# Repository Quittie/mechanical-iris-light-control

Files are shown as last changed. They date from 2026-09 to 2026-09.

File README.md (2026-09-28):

# Mechanical Iris for Light Intensity Control

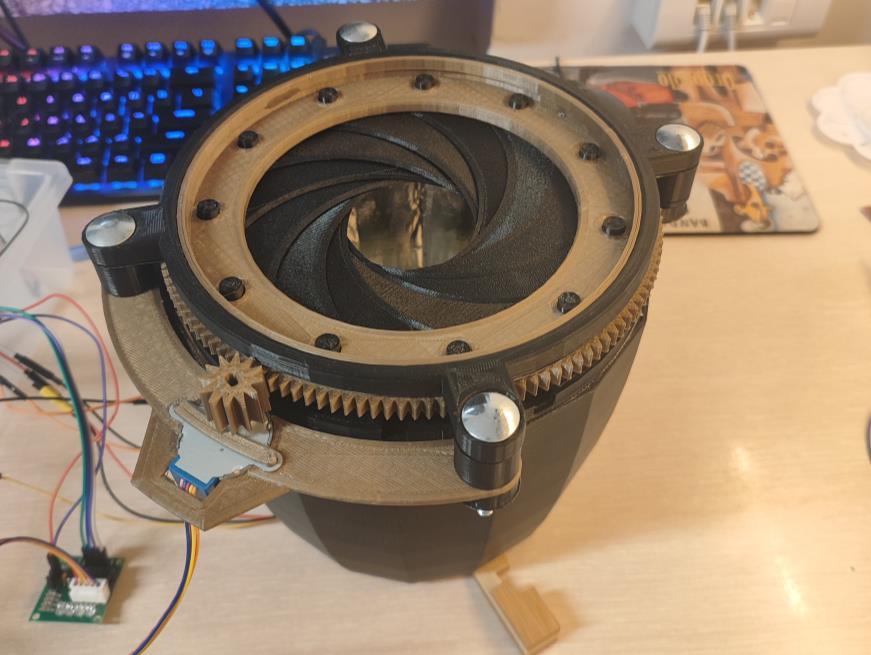
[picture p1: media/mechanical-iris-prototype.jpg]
Built mechanical iris


Microprocessor Systems course project, Poznań University of Technology, 2024/25.  
**Authors:** Piotr Trusiewicz and Michał Pietrzak.

The course assignment was to build an automatic regulation system. Michał and I chose to regulate the light level inside a chamber with a light sensor. A stepper motor opens or closes a printed mechanical iris, and an LED provides additional light when the aperture alone cannot reach the requested value. The target is set with a rotary encoder. An LCD shows the target and the reading from the sensor.

[Demonstration video 1](media/iris-demo-1.mp4) · [Demonstration video 2](media/iris-demo-2.mp4)

## My contribution

This was a team project, and I took part in the overall build and testing. My main responsibility was to choose a practical way to control how much light enters the chamber. I found [sketchpunk's Mechanical Iris](https://www.thingiverse.com/thing:773759) as a starting point, manually recreated and adapted the 3D design in Autodesk Inventor, assembled the mechanism, and fitted the electronic components into the prototype. The work described in our report includes changes to the stepper motor mount, the gear and the iris leaves.

The project and report are credited to both authors. The original iris design and its license are acknowledged in [the source notice](THIRD_PARTY_NOTICE.md).

## How it works

| Part | Role |
| --- | --- |
| Mechanical iris and 28BYJ-48 stepper motor | Adjust the opening of the light chamber |
| ULN2003 driver | Drive the stepper motor |
| BH1750 sensor | Measure light intensity inside the chamber |
| White LED | Add light when the iris reaches its useful limit |
| Rotary encoder | Set the requested light level |
| STM32 Nucleo-L476RG and 1.8-inch LCD | Control the system and display the values |

The motor turns a small gear which drives the larger ring around the iris. The gear ratio reported for this stage was 12:135. The rotating ring moves the leaves and changes the aperture.

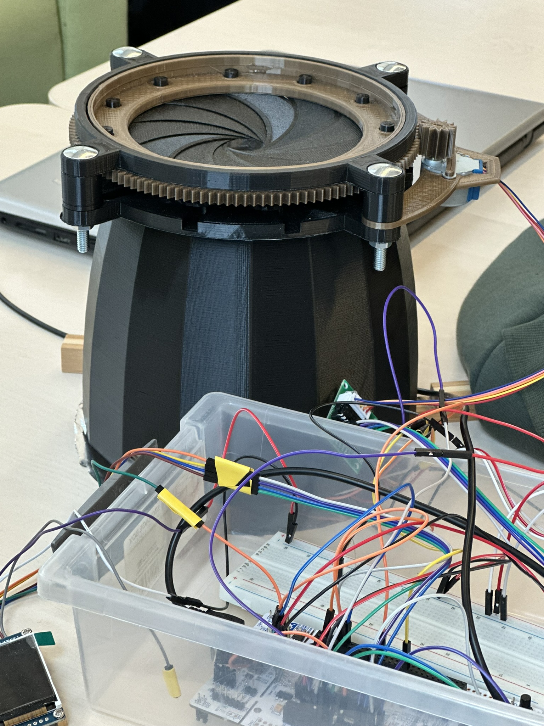
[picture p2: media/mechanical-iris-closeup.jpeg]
Close-up of the assembled iris


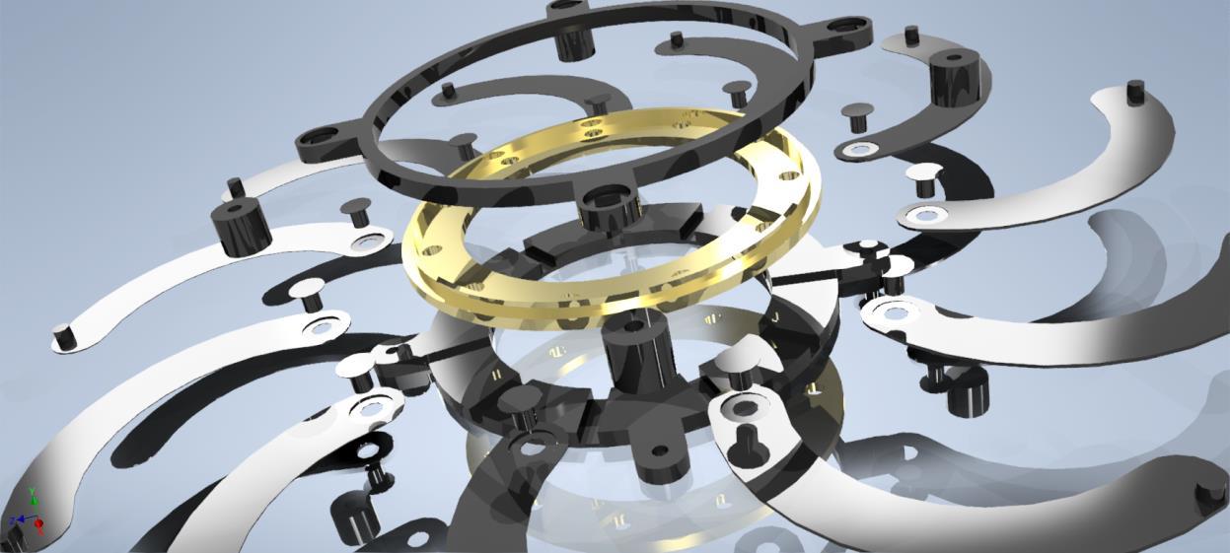
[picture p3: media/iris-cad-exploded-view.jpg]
CAD view of the iris assembly


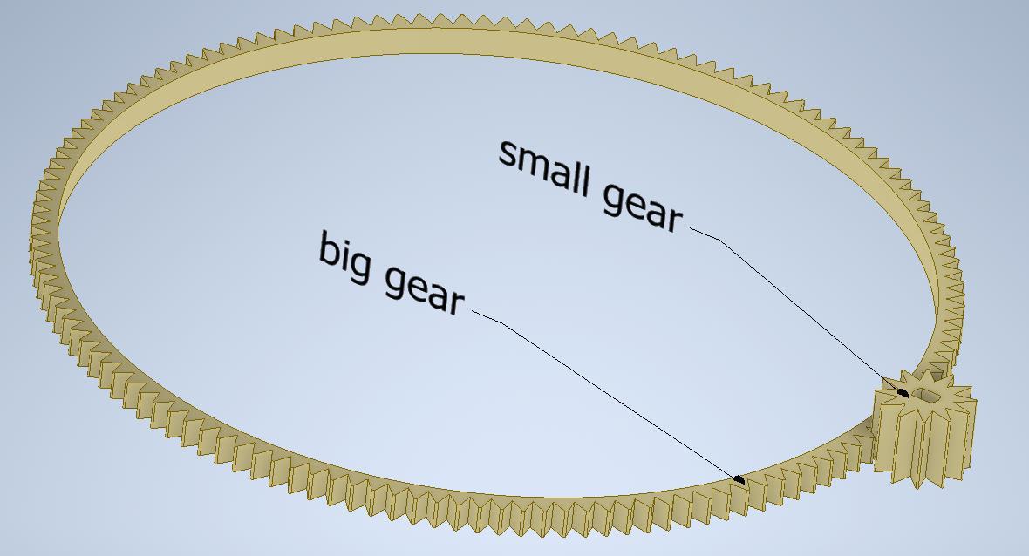
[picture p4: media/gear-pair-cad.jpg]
CAD view of the gear pair


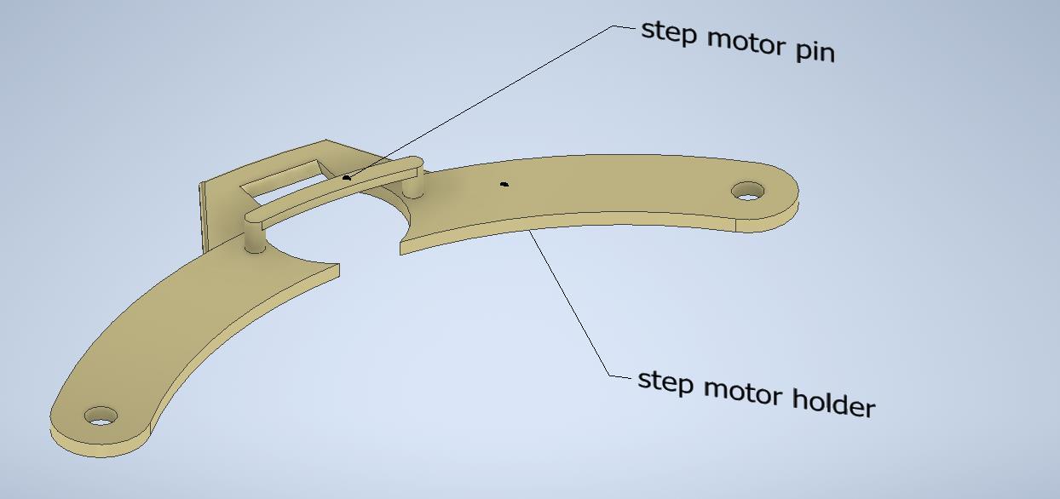
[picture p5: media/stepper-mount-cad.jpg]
CAD view of the motor mount


The prototype combined printed mechanical parts with a breadboard circuit and the Nucleo board. This photo shows the test setup, not a finished product enclosure.

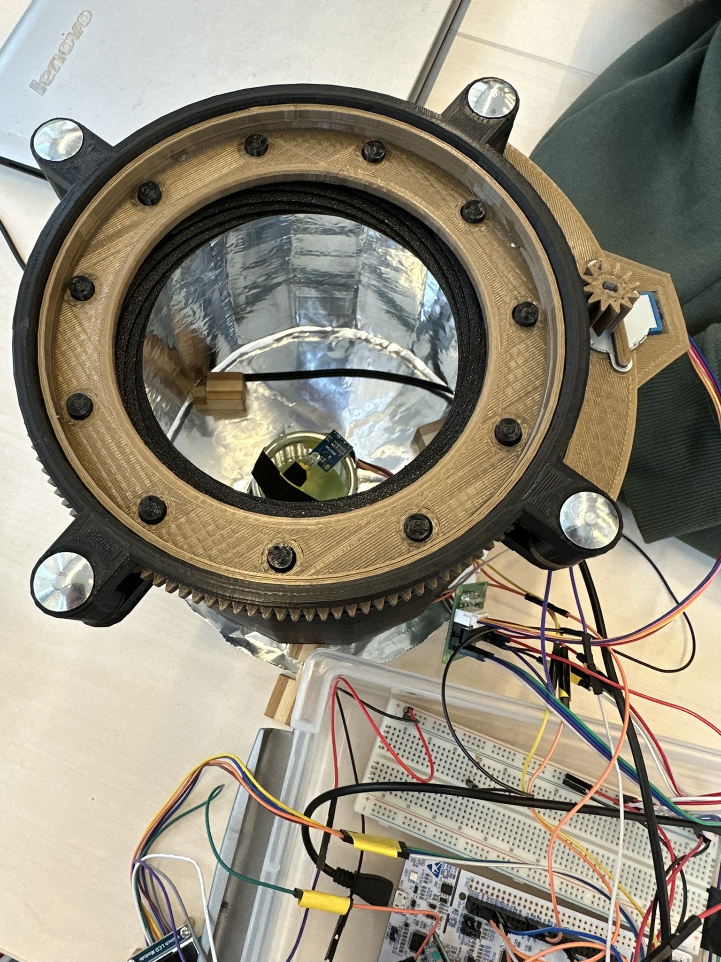
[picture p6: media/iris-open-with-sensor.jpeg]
Light sensor inside the chamber


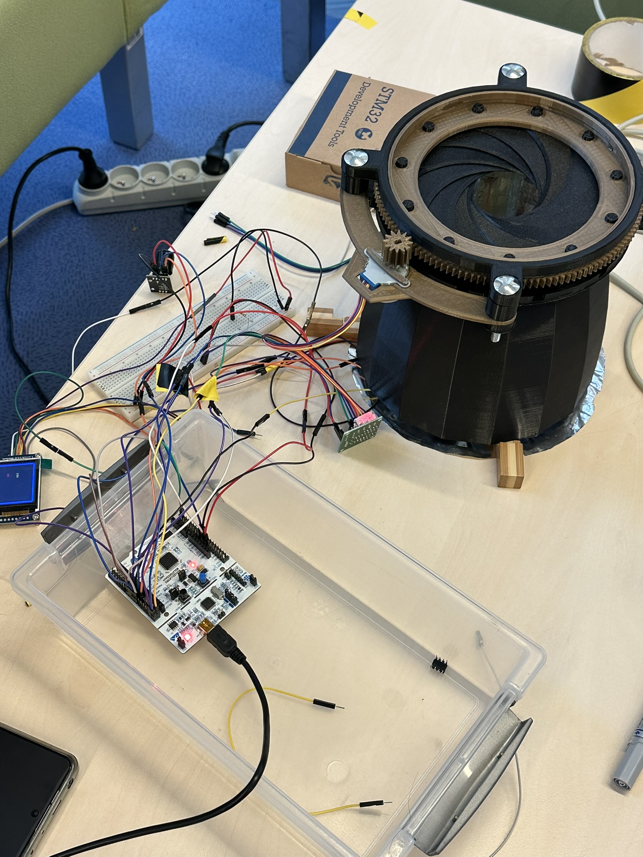
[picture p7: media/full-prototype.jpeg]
Complete prototype during testing


## Control tests

We compared three ways of approaching the requested light level. The red curves in the plots are setpoints and the blue curves are sensor readings. The plots come from our course report; they show this particular test setup.

| Method | What we observed |
| --- | --- |
| LED only | Small steady-state variation and little overshoot, but a slow response at the higher setpoint. |
| Iris only | Large overshoot and oscillations. Small mechanical movements were difficult to make reliably. |
| Iris and LED together | The first part still showed instability. At the next setpoint the iris reached a useful position and the LED brought the reading close to the target. |

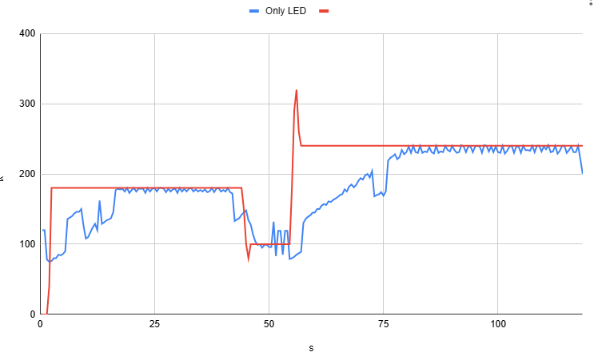
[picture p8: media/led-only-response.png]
LED-only test


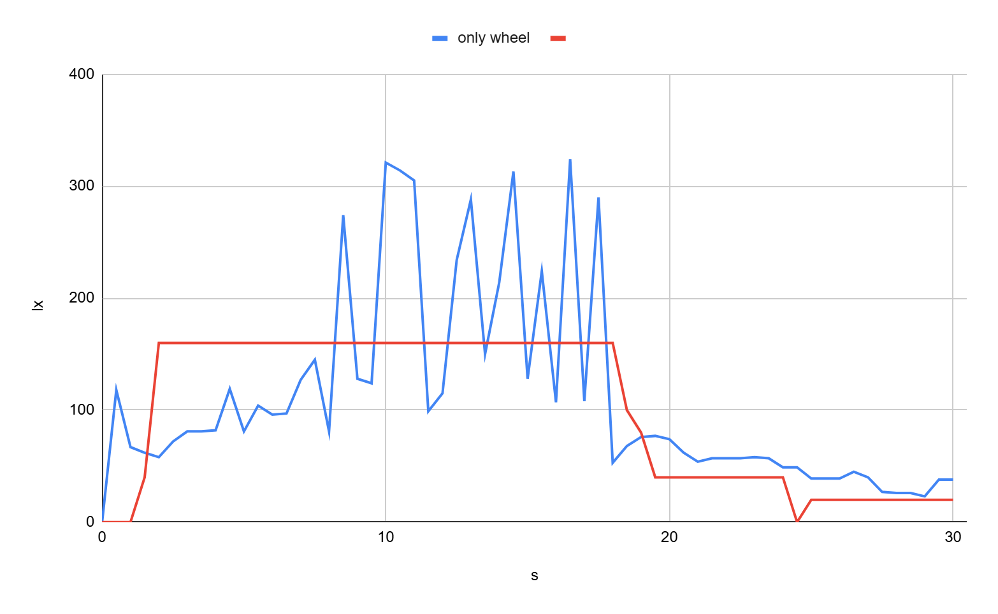
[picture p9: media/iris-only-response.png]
Iris-only test


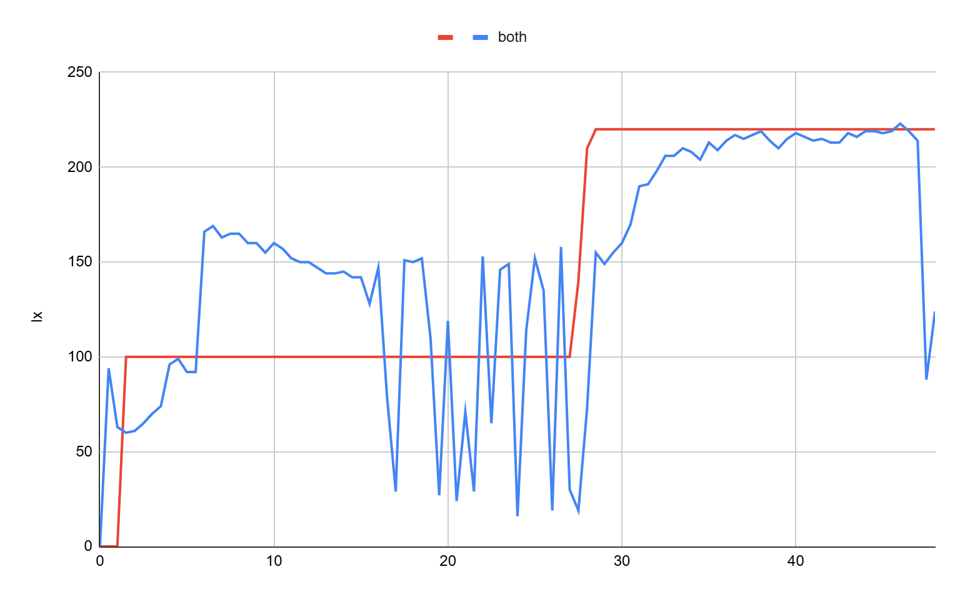
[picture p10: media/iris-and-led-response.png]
Combined iris and LED test


The tests showed why a mechanical aperture and an LED can complement each other, but they also exposed the limitations of the printed mechanism. The iris needed better control of small movements before it could regulate light smoothly on its own.

## Selected CAD files

These Autodesk Inventor part files are from the adapted project. The archive also contains source files from Thingiverse, which are not included here.

| File | Original file name |
| --- | --- |
| [Iris project](models/iris-project.ipt) | `projekt.ipt` |
| [Mount](models/mount.ipt) | `uchwyt.ipt` |
| [Gear](models/gear.ipt) | `zebaty.ipt` |

The Inventor files are design records. They are not a complete build package or tested print instructions. Attribution and non-commercial conditions of the original design still matter for any reuse.

## Report and source

The [full course report](docs/light-intensity-control-report.pdf) contains the circuit connections, more photos, control examples and test plots. It is credited to both project authors. The CAD concept is based on the [original Mechanical Iris by sketchpunk](https://www.thingiverse.com/thing:773759), with changes documented in our report. See [the source notice](THIRD_PARTY_NOTICE.md) before reusing any design files or images.

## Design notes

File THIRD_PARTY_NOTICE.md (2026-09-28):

# Design source and attribution

The mechanical iris used in this course project was based on **Mechanical Iris by sketchpunk**: https://www.thingiverse.com/thing:773759

The downloaded source folder contains a `LICENSE.txt` stating: “This thing was created by Thingiverse user sketchpunk, and is licensed under Creative Commons - Attribution - Non-Commercial”. It does not state a license version. The 3D model was manually recreated and adapted for the course prototype; the report describes changes to the stepper motor mount, the gear and the iris leaves.

The project report is jointly authored by **Piotr Trusiewicz and Michał Pietrzak**. Images extracted from it are shown here as records of our prototype and tests. This repository does not grant permission to use the original design commercially or to remove its attribution.

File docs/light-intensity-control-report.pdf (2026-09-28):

# POZNAŃ UNIVERSITY OF TECHNOLOGY

## FACULTY OF CONTROL, ROBOTICS AND ELECTRICAL ENGINEERING

## INSTITUTE OF ROBOTICS AND MACHINE INTELLIGENCE

## DIVISION OF CONTROL AND INDUSTRIAL ELECTRONICS

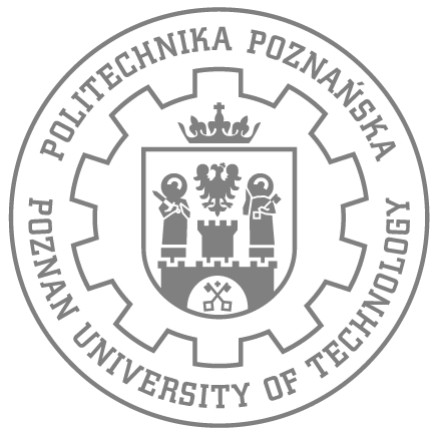
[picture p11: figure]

# Light Intensity Control System

# MICROPROCESSOR SYSTEMS

### LABORATORY REPORT

MICHAŁ PIETRZAK, 155315
MICHAL.PIETRZAK@STUDENT.PUT.POZNAN.PL

PIOTR TRUSIEWICZ 155322
PIOTR.TRUSIEWICZ@STUDENT.PUT.POZNAN.PL

### INSTRUCTOR:

ADRIAN WÓJCIK, M.SC.

ADRIAN.WOJCIK@PUT.POZNAN.PL

13-12-2024

Microprocessor systems:
Poznań University of Technology, Institute of Robotics and Machine Intelligence, Division of Control and Industrial Electronics

## Contents

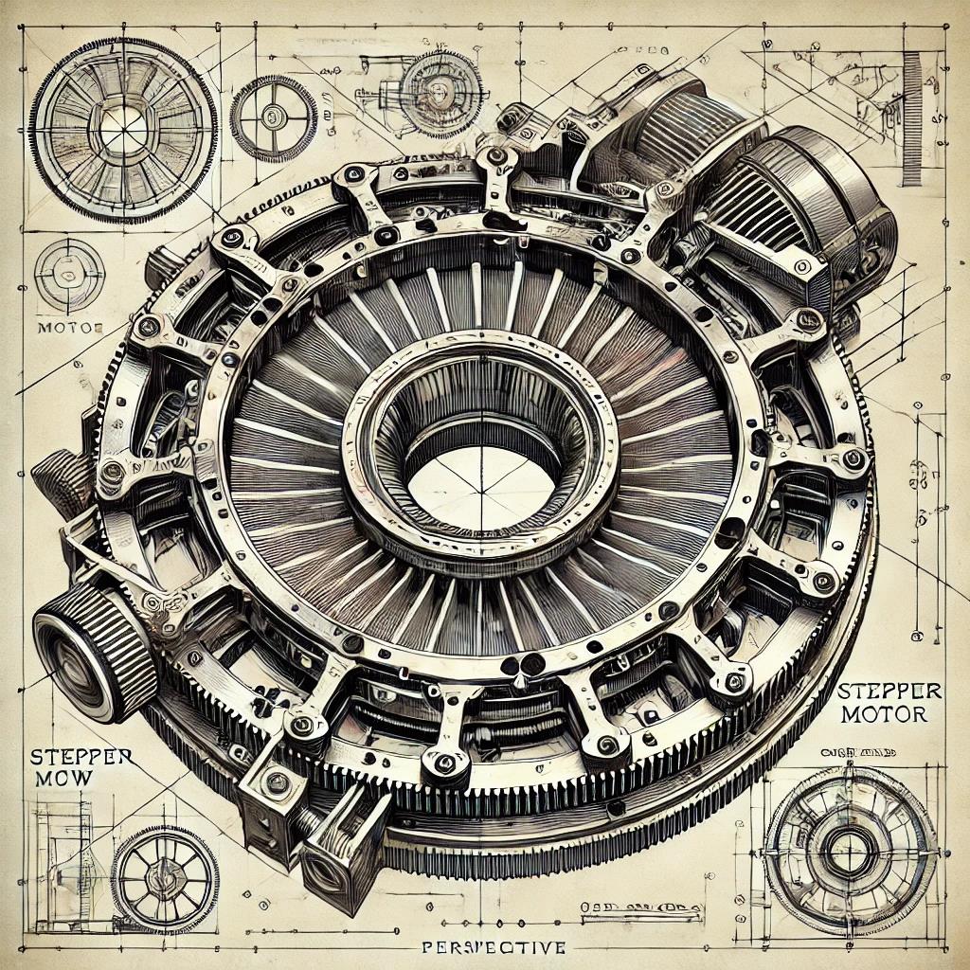
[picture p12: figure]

1

1

### 1. INTRODUCTION AND PURPOSE

The goal of our project was to create a system that controls the amount of light inside a chamber where a sensor is placed. We opted for a mechanical solution inspired by the human eye—designing a movable iris that smoothly adjusts the amount of incoming light.

The system is powered by a stepper motor, ensuring precise and fast regulation of the aperture. The entire setup is controlled by a Nucleo L476RG board, with the desired value adjustable via a rotary knob. Real-time readings from both the sensor and the knob are displayed on an LCD screen.

Since the ambient lighting conditions may be insufficient, we integrated an LED to illuminate the inside of the chamber. This LED also allows for fine-tuning the light intensity to achieve the exact lumen value when the iris mechanism alone is not enough.

Our project has a wide range of applications. It can regulate the amount of light delivered to environments such as greenhouses and can also serve as an educational tool for learning control systems.

Photo 1. Final photo of the mechanism

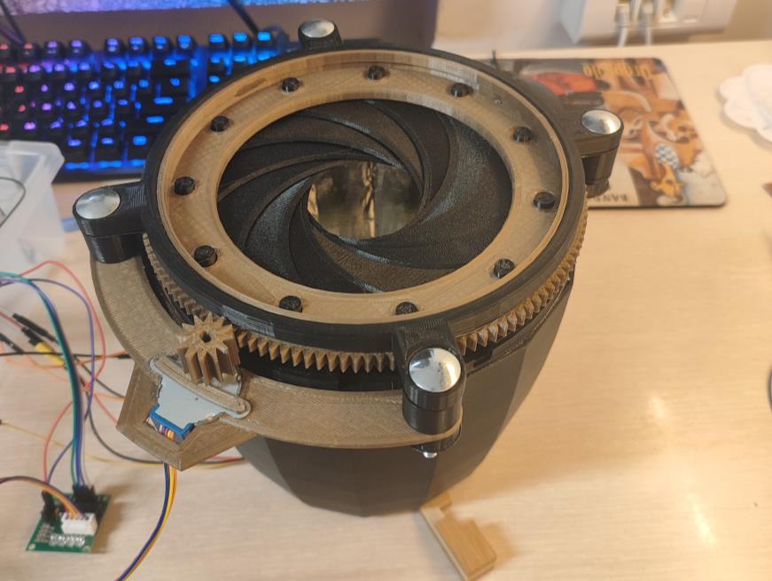
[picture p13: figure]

## 2. MODEL 3D

The 3D model of our project was based on an existing design found on Thingiverse. It underwent a series of modifications and improvements to achieve better performance. We added a stepper motor mount, a more precise gear, and redesigned the iris blades, which were trimmed towards the shorter edge to enhance their functionality.

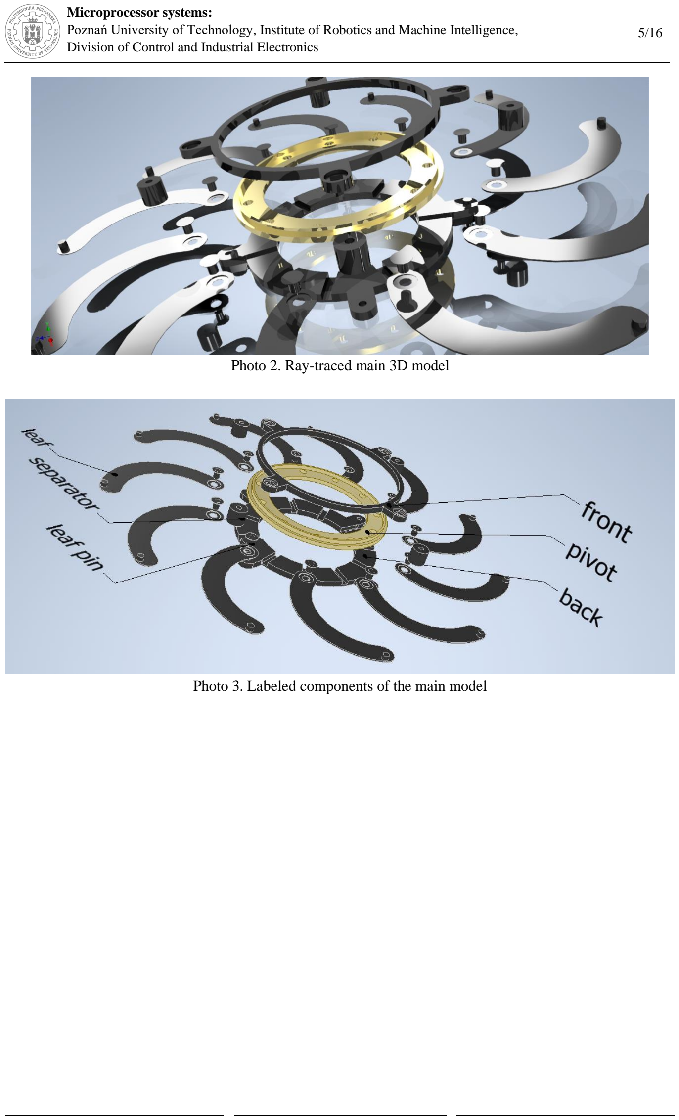
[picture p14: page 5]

Photo 2. Ray-traced main 3D model

Photo 3. Labeled components of the main model

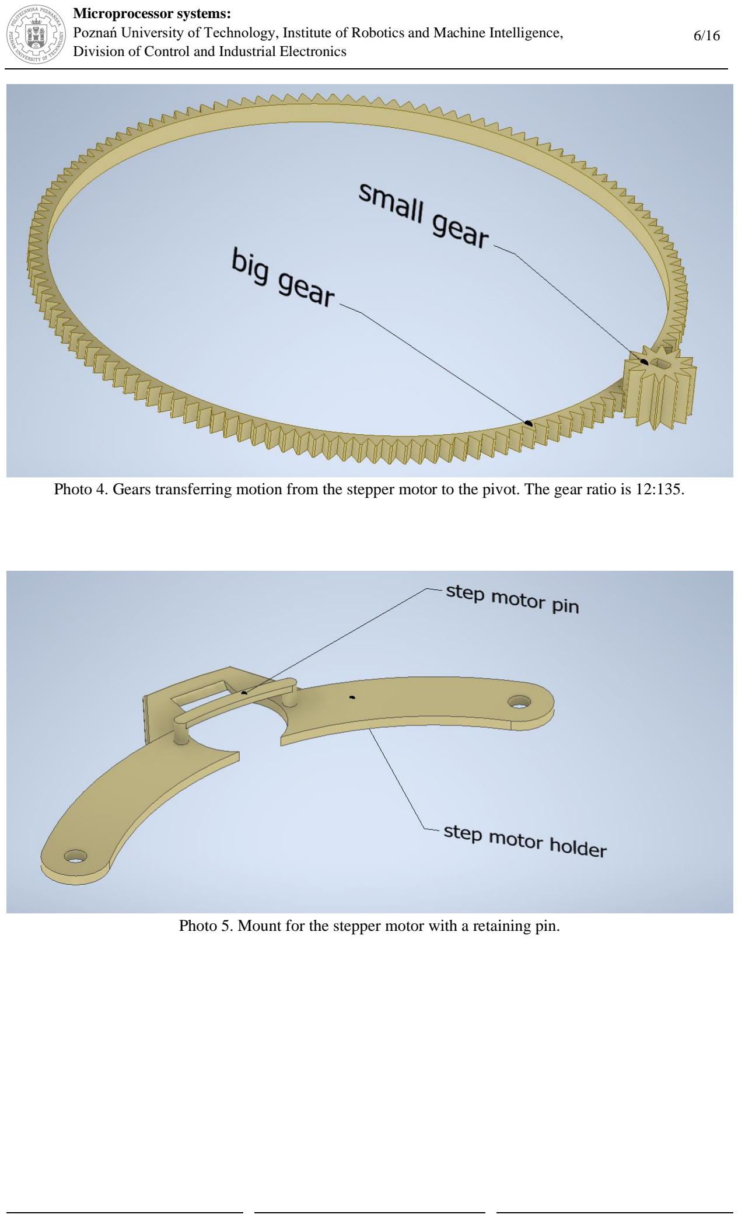
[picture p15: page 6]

Photo 4. Gears transferring motion from the stepper motor to the pivot. The gear ratio is 12:135.

Photo 5. Mount for the stepper motor with a retaining pin.

### 3. SYSTEMS

1. Light Sensor BH1750

The sensor measures the light intensity inside the chamber and transmits the data to the microcontroller, enabling precise light regulation. It is a digital light intensity sensor operating in the range of 1 - 65,535 lx, with a resolution of 1 or 4 lx depending on the selected mode. It communicates via the I2C (TWI) interface using two lines: data (SDA) and clock (SCL).

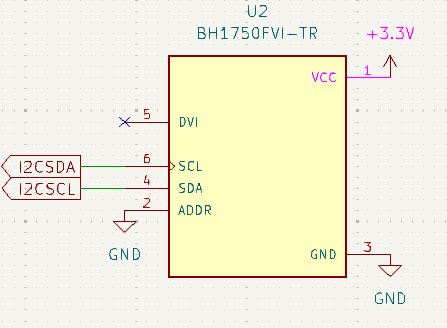
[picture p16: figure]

Scheme 1. Connection of the light sensor BH1750

2. Stepper motor with gearbox 28BYJ-48 with ULN2003 .

The stepper motor with a built-in 1:64 gearbox, powered by 5V and controlled by a dedicated module. It features a 4-phase step, a 5 mm shaft diameter (without flats), and 35 mm mounting hole spacing. It precisely controls the iris opening by converting electrical pulses into rotational motion. The built-in gearbox increases torque, ensuring smooth and accurate regulation of light inside the chamber.

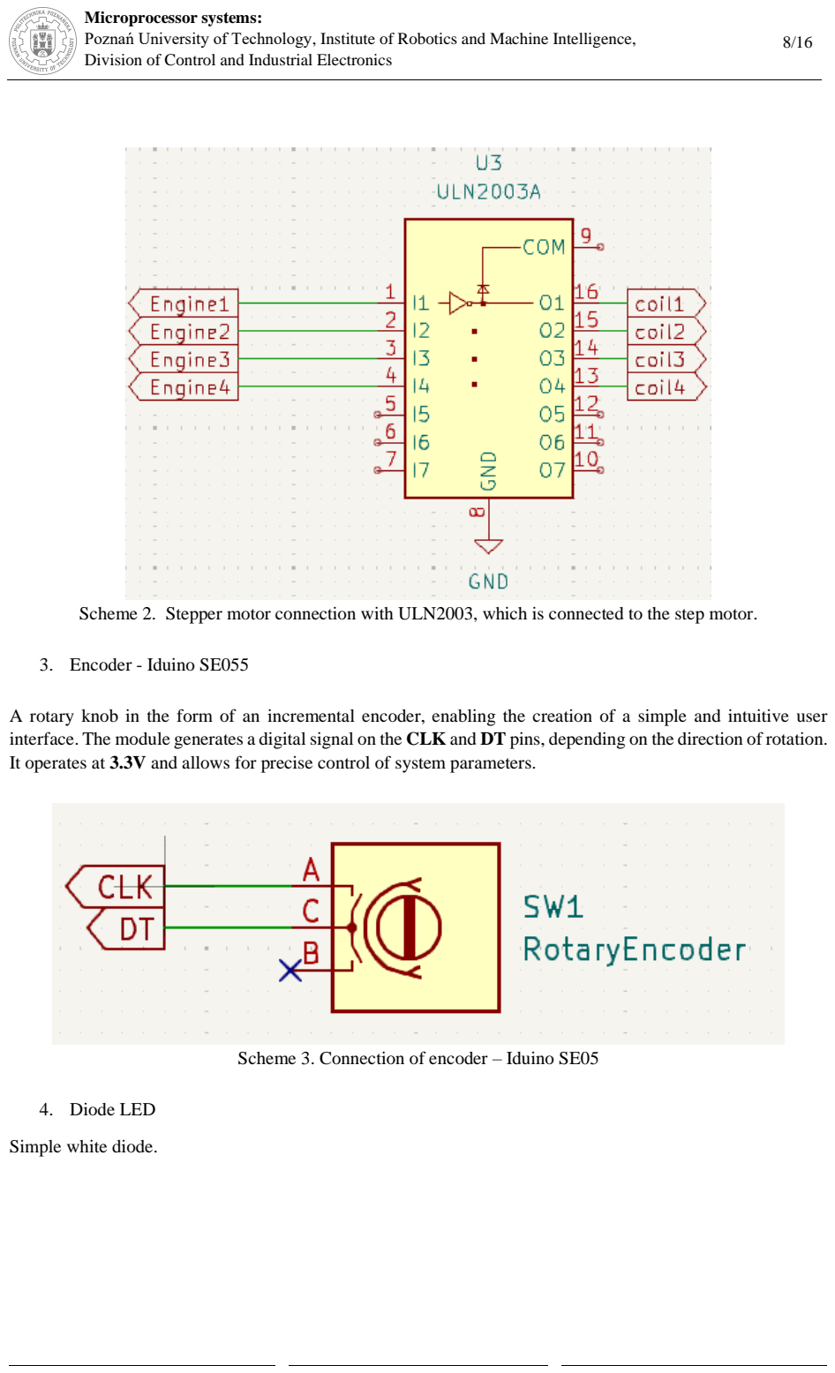
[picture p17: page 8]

Scheme 2. Stepper motor connection with ULN2003, which is connected to the step motor.

3. Encoder - Iduino SE055

A rotary knob in the form of an incremental encoder, enabling the creation of a simple and intuitive user interface. The module generates a digital signal on the CLK and DT pins, depending on the direction of rotation. It operates at 3.3V and allows for precise control of system parameters.

Scheme 3. Connection of encoder – Iduino SE05

4. Diode LED

Simple white diode.

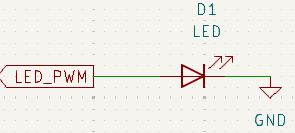
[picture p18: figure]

Scheme 4. diode LED connection

5. LCD

A 1.8" color LCD TFT display with a resolution of 128 x 160 px. Based on the ST7735S driver, it operates at 3.3V and communicates via SPI. It displays the values set by the encoder and the measured light intensity from the sensor. The CS line is active low.

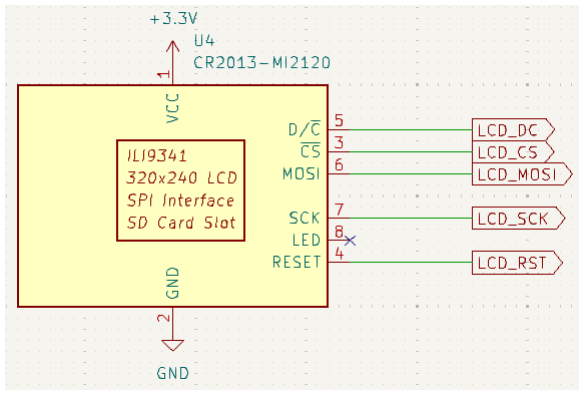
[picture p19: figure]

Scheme 5. LCD’s connection

6. Nucleo L476RG

The Nucleo module features a 32-bit STM32L476RG microcontroller, based on an ARM Cortex-M4 core running at 80 MHz. It includes 1 MB of Flash memory and 128 kB of RAM. The board is mbed-compatible and equipped with connectors for Arduino Shield add-ons. It supports popular development environments such as Keil, IAR, and GCC-based toolchains. The module also features a built-in ST-Link debugger/programmer, making programming and system diagnostics easier.

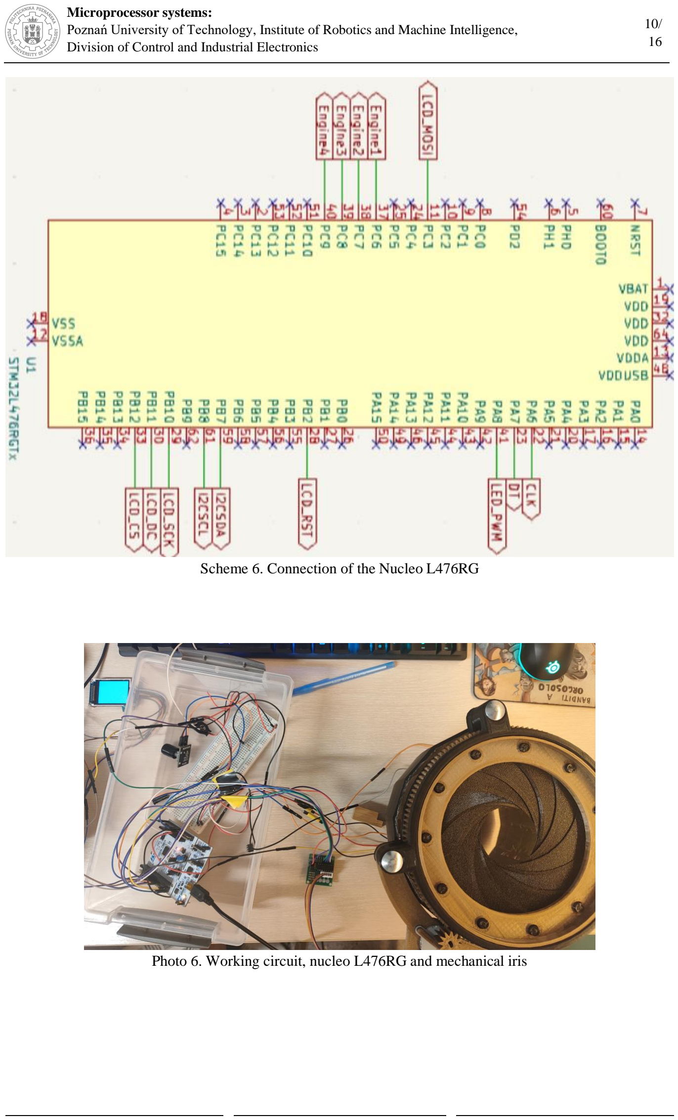
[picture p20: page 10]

Scheme 6. Connection of the Nucleo L476RG

Photo 6. Working circuit, nucleo L476RG and mechanical iris

### 4. PERFORMANCE

All graphs show the measured sensor value (blue line) and the set value (red line) as a function of time (horizontal axis). The sampling time is 0.5s.

1. As we can see in the diagram, when the LED was operating with the I-controller, we achieved significant gains, but some overshoots were observed. Additionally, certain steady-state disturbances appeared, and we encountered difficulties in eliminating them.

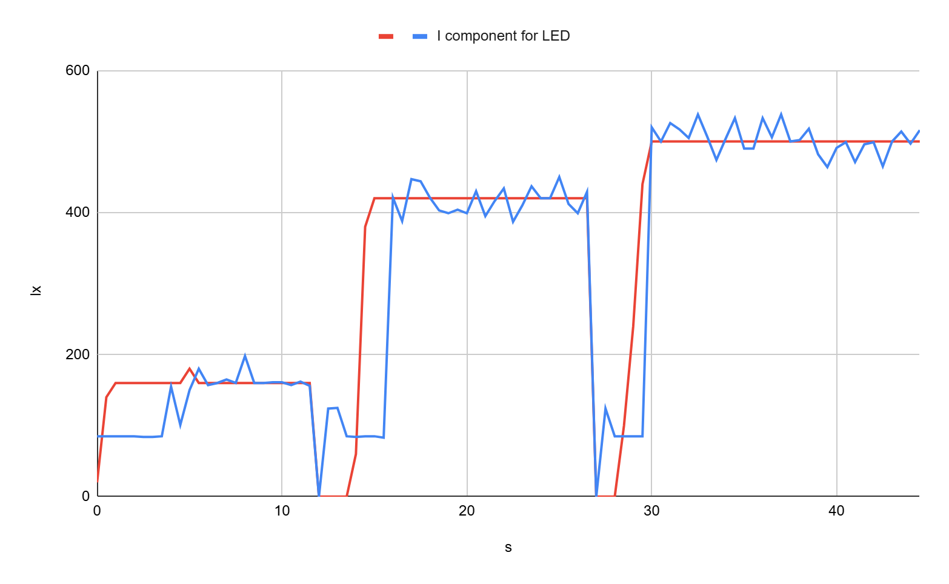
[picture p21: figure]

Diagram 1.

1. int light =0;
2. int value = 0;
3. int mode = 0;
4. int pulse = 0;
5. uint8_t ster = 0; // Control variable (1 = diode, 0 = stepper motor)
6. uint8_t engineR = 0; // Stepper motor control (1 = closing, 0 = opening)
7. float currentAngle = 0; // Stepper motor current position
8. int maxAngle = 875; // Max rotation angle
9. int minAngle = 20; // Min rotation angle
10. // PID constants (tune these values)
11. float Kp = 0;
12. float Ki = 5.3;
13. float Kd = 0;
14. // PID variables
15. float error = 0;
16. float previous_error = 0;

17. float integral = 0;
18. float derivative = 0;
19. float output = 0;
20. float dt = 0.5; // Sampling time in seconds 21.
22. void updatePID() {
23. // Calculate error
24. error = value - light;
25.
26. // Update integral with anti-windup
27. integral += error * dt;
28. if (integral > INTEGRAL_MAX) integral = INTEGRAL_MAX;
29. if (integral < INTEGRAL_MIN) integral = INTEGRAL_MIN; 30.
31. // Calculate derivative
32. derivative = (error - previous_error) / dt;
33.
34. // Compute PID output
35. output = (Kp * error) + (Ki * integral) + (Kd * derivative); 36.
37. // Clamp output to valid PWM range
38. if (output > PWM_MAX) output = PWM_MAX;
39. if (output < PWM_MIN) output = PWM_MIN; 40.
41. // Store error for next iteration
42. previous_error = error;
43. }
44.
45. void control_logic() {
46. updatePID();
47. TIM1->CCR1 = (uint32_t)output; // Set PWM output
48. // } else {
49. // Control stepper motor based on light
50. if (light >= value) {
51. engineR = 1; // Close
52. } else {
53. engineR = 0; // Open
54. }
55.
56. // Stepper motor movement with angle constraints
57. if (engineR == 1 && currentAngle <= maxAngle) {
58. stepper_step_angle(STEPPER_STEP_SIZE, 0, 12);
59. currentAngle += STEPPER_STEP_SIZE;
60. } else if (engineR == 0 && currentAngle >= minAngle) {
61. stepper_step_angle(STEPPER_STEP_SIZE, 1, 12);
62. currentAngle -= STEPPER_STEP_SIZE; }}
63. while (1) {
64. control_logic();
65. HAL_Delay(500);}

When we shut down the control of the shutter and controlled only the LED using if(), we achieved smaller steady-state disturbances and almost no overshoot. However, the gains were quite small, which can be especially seen in the third part of the graph when the set value was 240. The LED took a significant amount of time to achieve enough brightness to reach this level inside our tube.


Diagram 2.

While(1) {HAL_Delay(200); if (mode==1){

66. pulse = (pulse + 5 > 10000) ? 10000 : pulse + 1; // increase by 1
67. } else {
68. pulse -= 5; // Decrease pulse by 5
69. if (pulse < 0) {
70. pulse = 0; // Clamp pulse to 0}}
71. if (light >= value) {
72. mode = 0;}
73. if (light < value) {
74. mode = 1;}
75. TIM1->CCR1 = pulse;}
2. When we shut down the LED and controlled only the shutter, we observed significant overshoot and large oscillations in the steady state. This occurred because our shutter had difficulties with small movements, leading to overshooting during both opening and closing.


Diagram 3.

76. while (1){
77. HAL_Delay(200);
78. if (light >= 20+value) {
79. engineR = 1; // Close
80. } else if(light < value-20){
81. engineR = 2; // Open
82. }
83. else{
84. engineR = 0;}
85. // Stepper motor movement with angle constraints
86. if (engineR == 1 && currentAngle <= maxAngle) {
87. stepper_step_angle(STEPPER_STEP_SIZE, 0, 10);
88. currentAngle += STEPPER_STEP_SIZE;
89. } else if (engineR == 2 && currentAngle >= minAngle) {
90. stepper_step_angle(STEPPER_STEP_SIZE, 1, 10);
91. currentAngle -= STEPPER_STEP_SIZE;
92. }}

3. When we controlled both the shutter and the LED, we achieved quite good gains and, at times, a stable steady state. This can be observed in the graph. Initially, the shutter overshot and had some difficulty reaching a steady state. However, at the second set value, it achieved a good position, allowing the LED to take control and reach an almost perfect steady state.


Diagram 4.

93. while (1){
94. HAL_Delay(200);
95. if (light >= 20+value) {
96. engineR = 1; // Close
97. } else if(light < value-20){
98. engineR = 2; // Open
99. }
100. else{
100. engineR = 0;
}
101. // Stepper motor movement with angle constraints
102. if (engineR == 1 && currentAngle <= maxAngle) {
103. stepper_step_angle(STEPPER_STEP_SIZE, 0, 10);
104. currentAngle += STEPPER_STEP_SIZE;
105. } else if (engineR == 2 && currentAngle >= minAngle) {
106. stepper_step_angle(STEPPER_STEP_SIZE, 1, 10);
107. currentAngle -= STEPPER_STEP_SIZE;
108. }
109. if (mode==1){
110. pulse = (pulse + 5 > 10000) ? 10000 : pulse + 1; // increase by 1
111. } else {

112. pulse -= 5; // Decrease pulse by 5
113. if (pulse < 0) {
114. pulse = 0; // Clamp pulse to 0
115. }
116. }
117. if (light >= value) {
118. mode = 0;
119. }
120. if (light < value) {
121. mode = 1;
122. }
123. TIM1->CCR1 = pulse;}

### 5. REFERENCES & SOURCES

1. Thingverse mechanical iris 3D model by sketchpunk: https://www.thingiverse.com/thing:773759
2. We sincerely thank Mgr inż. Joanna Piasek-Skupna for her invaluable expertise and support.

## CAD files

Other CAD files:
models/gear.ipt
models/iris-project.ipt
models/mount.ipt

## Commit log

2026-09-28 Add prototype photos, test plots and demo videos
2026-09-28 Add joint course report
2026-09-28 Add selected Inventor CAD models
    [gear.ipt, iris-project.ipt, mount.ipt]
